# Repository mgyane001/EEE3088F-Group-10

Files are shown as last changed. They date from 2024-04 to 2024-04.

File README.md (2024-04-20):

# EEE3088F Group 10 Micro-Mouse Project 2024

## Project Overview
The goal of the Micro-Mouse Project is designing and building a maze-solving robot, inspired by the principles and competition of Micro-Mouse robots. This project focuses on the hardware development of the robot, particularly the sensing and power subsystems, while integrating provided processor and motherboard modules.

### Components
- **Processor Module:** Utilizes a STM32L476 microcontroller for processing and programming.
- **Motherboard Module:** Serves as the foundational circuit board connecting all the other modules.
- **Sensing Module:** Designed to detect obstacles, aiding the robot in navigation.
- **Power Module:** Manages power distribution, motor operation, and battery charging.

## Installation & Setup
This section will guide you through setting up your development environment and assembling the Micro-Mouse robot.

### Prerequisites
- STM32CubeIDE for firmware development.
- Basic soldering equipment and electronic component handling knowledge.
- KiCad or any other electronics CAD software

### Assembly Instructions
1. **Processor & Motherboard Connection:** Start by connecting the processor module to the motherboard using the provided pin headers.
2. **Sensing Module Assembly:** Follow the schematic in `Docs/Sensing_Module_Schematic.pdf` to assemble your sensing module. Attach it to the motherboard as indicated.
3. **Power Module Assembly:** Assemble the power module according to `Docs/Power_Module_Schematic.pdf` and attach it to the designated motherboard location.
4. **Final Assembly:** Secure all connections and mount the assembled motherboard into the chassis and connect the motors and battery.

## Usage
To operate the Micro-Mouse:
1. **Firmware Upload:** Use STM32CubeIDE to open the project from `Firmware/` and flash it onto the processor module.
2. **Power On:** Switch on the Micro-Mouse using the power module's ON/OFF switch.
3. **Maze Testing:** Place the Micro-Mouse at the start of a maze and observe its operation and maze-solving capability.

## Contributing
We welcome contributions to the Micro-Mouse Project! If you have suggestions, improvements, or bug fixes, please follow the steps below:
1. Fork the repository.
2. Create a new branch (`git checkout -b feature/AmazingFeature`).
3. Commit your changes (`git commit -m 'Add some AmazingFeature'`).
4. Push to the branch (`git push origin feature/AmazingFeature`).
5. Open a pull request.

## Project Structure
- `/Firmware`: Contains all firmware code for the Micro-Mouse.
- `/Docs`: Documentation, including module schematics and assembly guides.
- `/Tools`: Auxiliary tools for development and testing.
- `/Designs`: CAD designs for optional chassis and mechanical parts.

## Support
For support, please open an issue in the repository or contact the project maintainers directly via email.

## Acknowledgements
- **Veritasium:** For the inspirational content on Micro-Mouse robots.
- **STM32L476 Community:** For resources and support in firmware development.

## License
This project is licensed under the MIT License - see the `LICENSE` file for details.

---

We hope this project inspires and educates all participants and observers alike. Happy building!

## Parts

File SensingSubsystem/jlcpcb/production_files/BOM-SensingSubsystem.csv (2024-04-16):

Comment | Designator | Footprint | LCSC
BS170 | Q4,Q5,Q6 | TO-92_Inline | C111691
4.7u | C1,C2,C3 | C_0805_2012Metric | C19666
100 | R10,R4,R7 | R_0603_1608Metric | C22775
22 | R12,R6,R9 | R_0603_1608Metric | C23345
47k | R11,R5,R8 | R_0603_1608Metric | C25819
SFH 309 FA | Q1,Q2,Q3 | LED_D3.0mm_Horizontal_O1.27mm_Z10.0mm | C2900253
1.8k | R1,R2,R3 | R_0603_1608Metric | C4177
TSAL6200 | D1,D2,D3 | LED_D5.0mm_Horizontal_O1.27mm_Z15.0mm | C55528

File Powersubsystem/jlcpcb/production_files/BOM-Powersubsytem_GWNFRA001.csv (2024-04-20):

Comment | Designator | Footprint | LCSC
2.2uF | C1 | C_0402_1005Metric | C12530
BQ24092DGQR | U2 | IC_XTR111AIDGQR | C133237
10uF | C8 | C_0402_1005Metric | C15195
1k | R2,R4,R6,R7 | BO_CR0603 | C21190
2k | R3 | BO_CR0603 | C22975
100k | R1,R5 | BO_CR0603 | C25803
TS-1187A-B-A-B | S1 | SW_TS-1187A-B-A-B | C318884
DRV8833PWPR | U3 | IC_DRV8833PWPR | C50506
1uF | C6,C7 | C_0402_1005Metric | C52923
0.01uF | C4 | C_01005_0402Metric

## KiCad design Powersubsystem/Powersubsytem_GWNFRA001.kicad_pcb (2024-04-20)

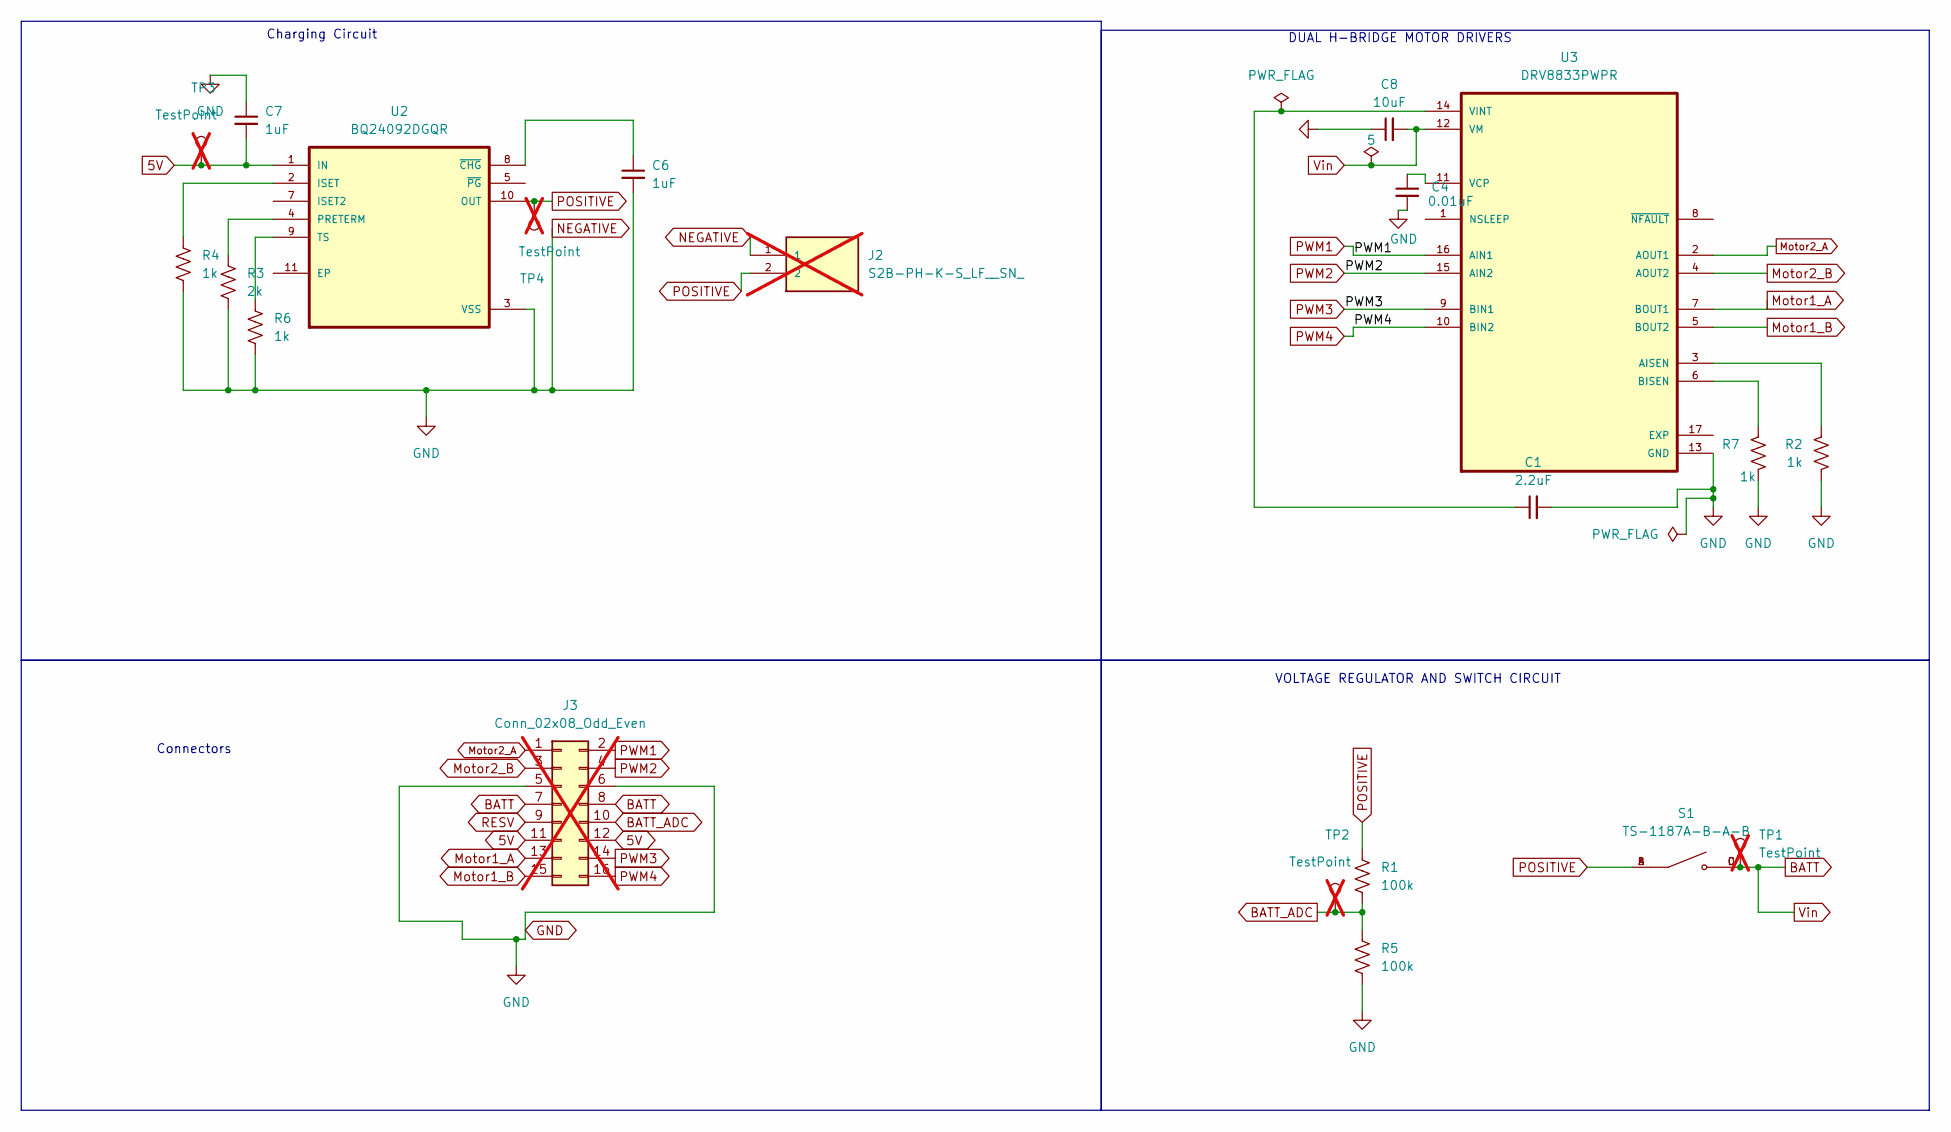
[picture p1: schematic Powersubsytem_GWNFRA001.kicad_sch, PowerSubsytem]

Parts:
C1: 2.2uF; C_0402_1005Metric
C4: 0.01uF; C_01005_0402Metric
C6, C7: 1uF; C_0402_1005Metric
C8: 10uF; C_0402_1005Metric
J2: S2B-PH-K-S_LF__SN_; JST_S2B-PH-K-S_LF__SN_; not fitted
J3: Conn_02x08_Odd_Even; PinHeader_2x08_P2.54mm_Vertical; not fitted
R1, R5: 100k; BO_CR0603
R2, R4, R6, R7: 1k; BO_CR0603
R3: 2k; BO_CR0603
S1: TS-1187A-B-A-B; SW_TS-1187A-B-A-B; PARTREV A0
TP1, TP2, TP3, TP4: TestPoint; TestPoint_THTPad_D1.0mm_Drill0.5mm; not fitted
U2: BQ24092DGQR; IC_XTR111AIDGQR
U3: DRV8833PWPR; IC_DRV8833PWPR; PARTREV E; LCSC C50506

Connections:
5V: C7.2, J3.11, J3.12, TP3.1, U2.1 (IN)
BATT: C8.2, J3.7, J3.8, S1.C, S1.D, TP1.1, U3.12 (VM)
BATT_ADC: J3.10, R1.2, R5.1, TP2.1
GND: C1.2, C4.2, C6.2, C7.1, C8.1, J2.1, J3.5, J3.6, R2.2, R3.2, R4.2, R5.2, R6.2, R7.2, U2.3 (VSS), U3.13 (GND)
Motor1_A: J3.13, U3.7 (BOUT1)
Motor1_B: J3.15, U3.5 (BOUT2)
Motor2_A: J3.1, U3.2 (AOUT1)
Motor2_B: J3.3, U3.4 (AOUT2)
unnamed: R4.1, U2.2 (ISET)
unnamed: R3.1, U2.4 (PRETERM)
unnamed: R6.1, U2.9 (TS)
unnamed: C6.1, U2.8 (~CHG)
unnamed: R2.1, U3.3 (AISEN)
unnamed: R7.1, U3.6 (BISEN)
unnamed: C4.1, U3.11 (VCP)
unnamed: C1.1, U3.14 (VINT)
POSITIVE: J2.2, R1.1, S1.A, S1.B, TP4.1, U2.10 (OUT)
PWM1: J3.2, U3.16 (AIN1)
PWM2: J3.4, U3.15 (AIN2)
PWM3: J3.14, U3.9 (BIN1)
PWM4: J3.16, U3.10 (BIN2)
RESV: J3.9

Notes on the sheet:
Charging Circuit
VOLTAGE REGULATOR AND SWITCH CIRCUIT
Connectors
DUAL H-BRIDGE MOTOR DRIVERS

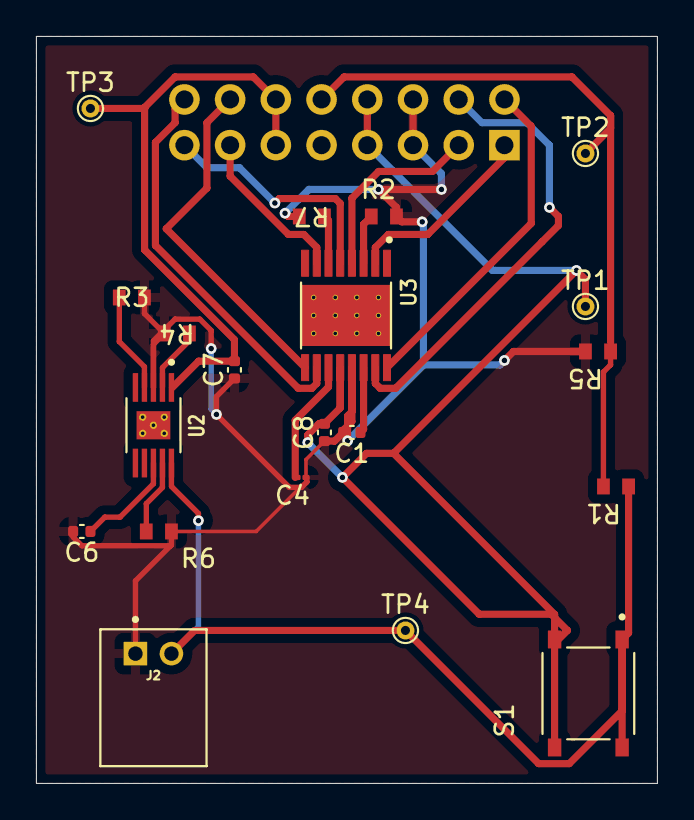
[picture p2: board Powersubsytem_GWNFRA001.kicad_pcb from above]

Board: 2 copper layers, 34.5 x 41.5 mm, 21 parts (1 on the bottom side), 21 nets.

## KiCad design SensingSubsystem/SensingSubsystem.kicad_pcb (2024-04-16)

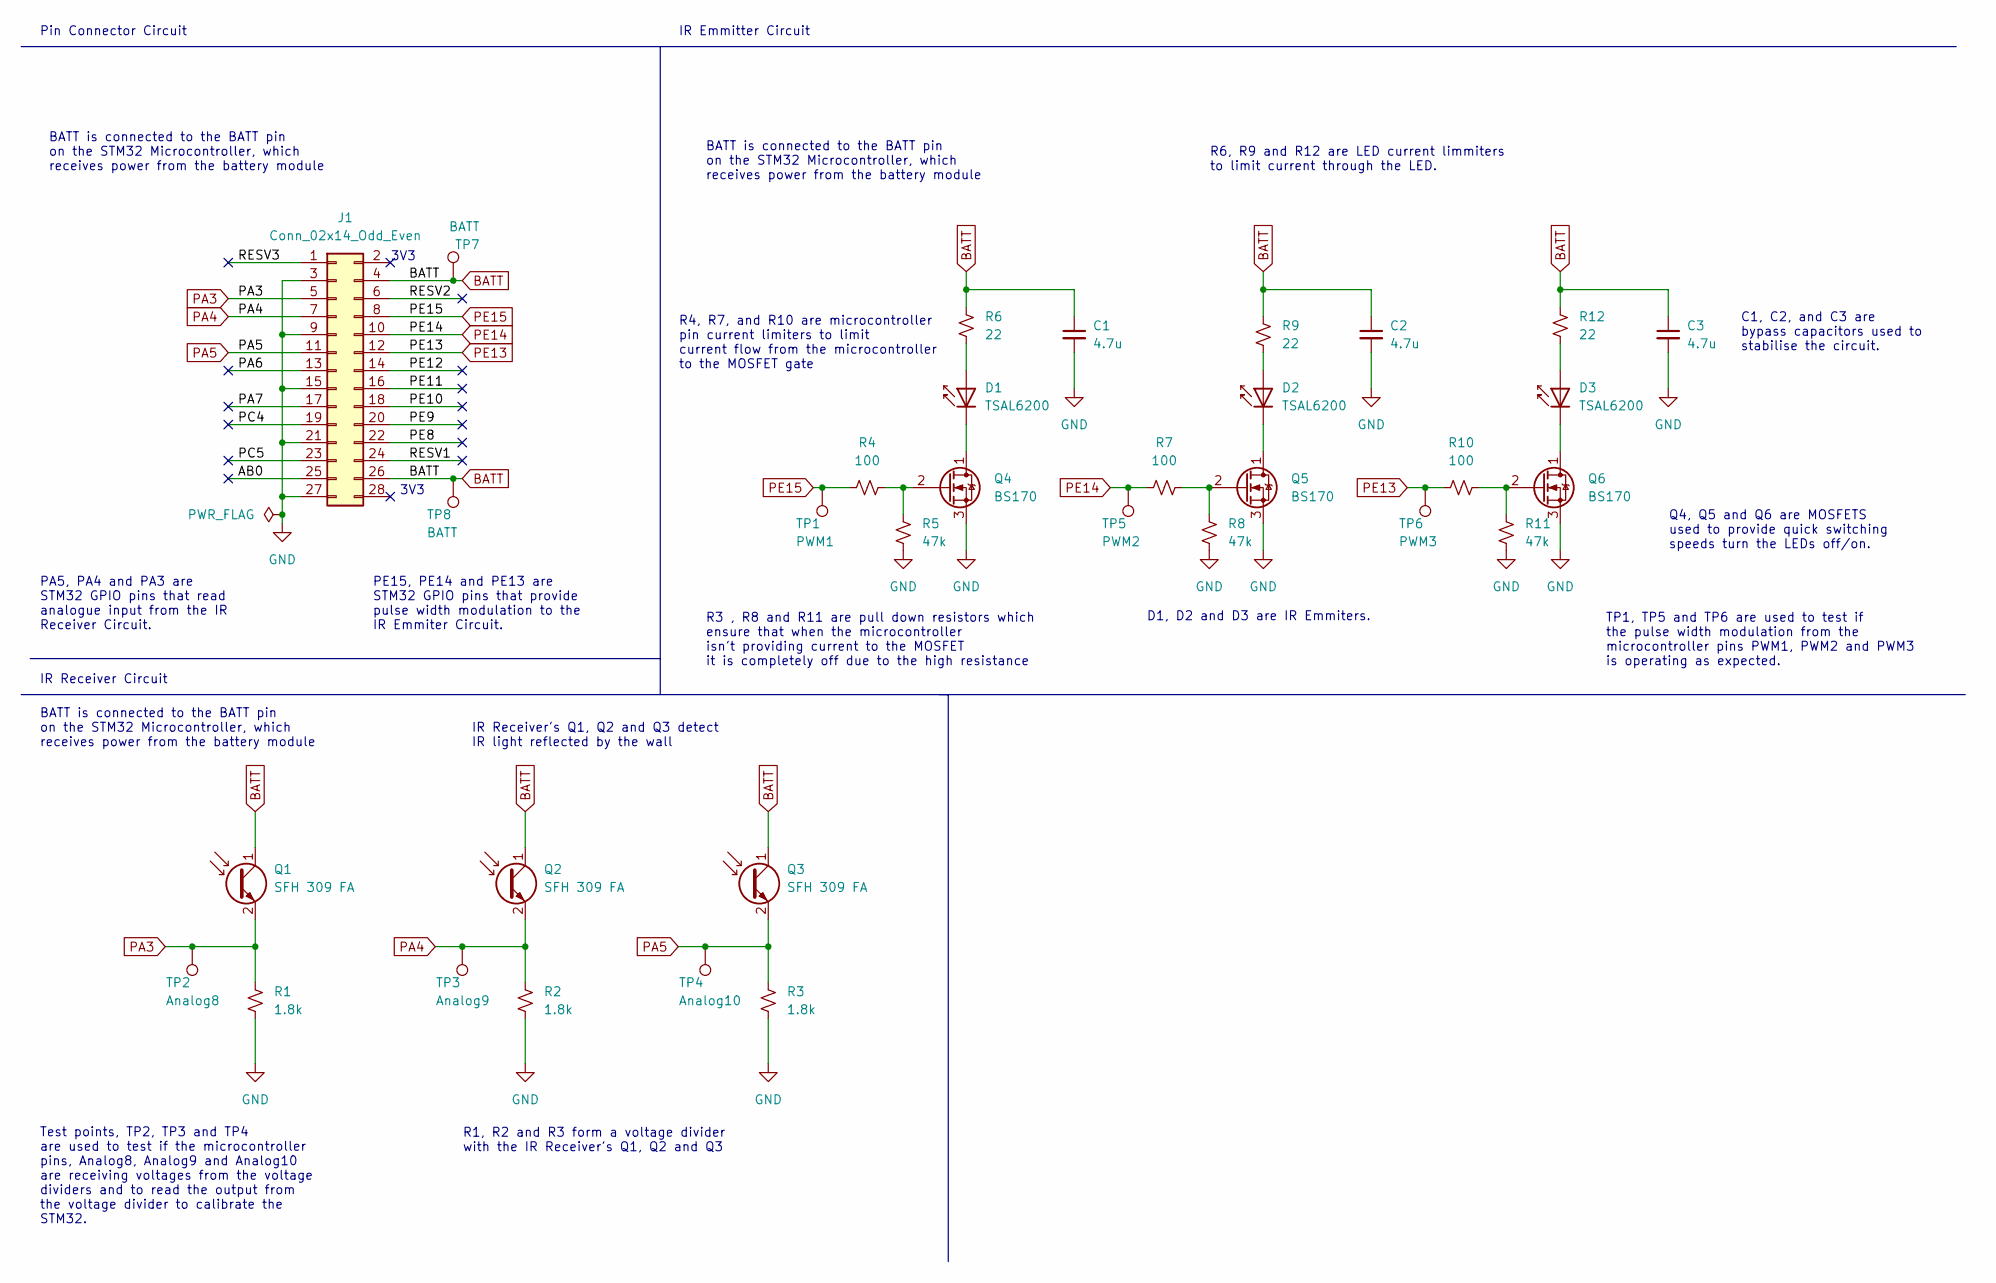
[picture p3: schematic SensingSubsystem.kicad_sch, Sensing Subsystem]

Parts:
C1, C2, C3: 4.7u; C_0805_2012Metric
D1, D2, D3: TSAL6200; LED_D5.0mm_Horizontal_O1.27mm_Z15.0mm
J1: Conn_02x14_Odd_Even; PinHeader_2x14_P2.54mm_Vertical
Q1, Q2, Q3: SFH 309 FA; LED_D3.0mm_Horizontal_O1.27mm_Z10.0mm
Q4, Q5, Q6: BS170; TO-92_Inline
R1, R2, R3: 1.8k; R_0603_1608Metric
R4, R7, R10: 100; R_0603_1608Metric
R5, R8, R11: 47k; R_0603_1608Metric
R6, R9, R12: 22; R_0603_1608Metric
TP1: PWM1; TestPoint_THTPad_D1.0mm_Drill0.5mm
TP2: Analog8; TestPoint_THTPad_D1.0mm_Drill0.5mm
TP3: Analog9; TestPoint_THTPad_D1.0mm_Drill0.5mm
TP4: Analog10; TestPoint_THTPad_D1.0mm_Drill0.5mm
TP5: PWM2; TestPoint_THTPad_D1.0mm_Drill0.5mm
TP6: PWM3; TestPoint_THTPad_D1.0mm_Drill0.5mm
TP7, TP8: BATT; TestPoint_THTPad_D1.0mm_Drill0.5mm

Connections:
/AB0: J1.25
/PA6: J1.13
/PA7: J1.17
/PC4: J1.19
/PC5: J1.23
/PE8: J1.22
/PE9: J1.20
/PE10: J1.18
/PE11: J1.16
/PE12: J1.14
/RESV1: J1.24
/RESV2: J1.6
/RESV3: J1.1
BATT: C1.1, C2.1, C3.1, J1.4, J1.26, Q1.1 (C), Q2.1 (C), Q3.1 (C), R6.1, R9.1, R12.1, TP7.1, TP8.1
GND: C1.2, C2.2, C3.2, J1.3, J1.9, J1.15, J1.21, J1.27, Q4.3 (S), Q5.3 (S), Q6.3 (S), R1.2, R2.2, R3.2, R5.1, R8.1, R11.1
unnamed: D1.1 (K), Q4.1 (D)
unnamed: D1.2 (A), R6.2
unnamed: D2.1 (K), Q5.1 (D)
unnamed: D2.2 (A), R9.2
unnamed: D3.1 (K), Q6.1 (D)
unnamed: D3.2 (A), R12.2
unnamed: Q4.2 (G), R4.2, R5.2
unnamed: Q5.2 (G), R7.2, R8.2
unnamed: Q6.2 (G), R10.2, R11.2
PA3: J1.5, Q1.2 (E), R1.1, TP2.1
PA4: J1.7, Q2.2 (E), R2.1, TP3.1
PA5: J1.11, Q3.2 (E), R3.1, TP4.1
PE13: J1.12, R10.1, TP6.1
PE14: J1.10, R7.1, TP5.1
PE15: J1.8, R4.1, TP1.1

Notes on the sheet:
R3 , R8 and R11 are pull down resistors which ensure that when the microcontroller isn't providing current to the MOSFET it is completely off due to the high resistance
IR Emmitter Circuit
C1, C2, and C3 are bypass capacitors used to stabilise the circuit.
PE15, PE14 and PE13 are STM32 GPIO pins that provide pulse width modulation to the IR Emmiter Circuit.
3V3
R6, R9 and R12 are LED current limmiters to limit current through the LED.
TP1, TP5 and TP6 are used to test if the pulse width modulation from the microcontroller pins PWM1, PWM2 and PWM3 is operating as expected.
BATT is connected to the BATT pin on the STM32 Microcontroller, which receives power from the battery module
Test points, TP2, TP3 and TP4 are used to test if the microcontroller pins, Analog8, Analog9 and Analog10 are receiving voltages from the voltage dividers and to read the output from the voltage divider to calibrate the STM32.
Pin Connector Circuit
PA5, PA4 and PA3 are STM32 GPIO pins that read analogue input from the IR Receiver Circuit.
IR Receiver's Q1, Q2 and Q3 detect IR light reflected by the wall
D1, D2 and D3 are IR Emmiters.
IR Receiver Circuit
Q4, Q5 and Q6 are MOSFETS used to provide quick switching speeds turn the LEDs off/on.
R4, R7, and R10 are microcontroller pin current limiters to limit current flow from the microcontroller to the MOSFET gate
R1, R2 and R3 form a voltage divider with the IR Receiver's Q1, Q2 and Q3

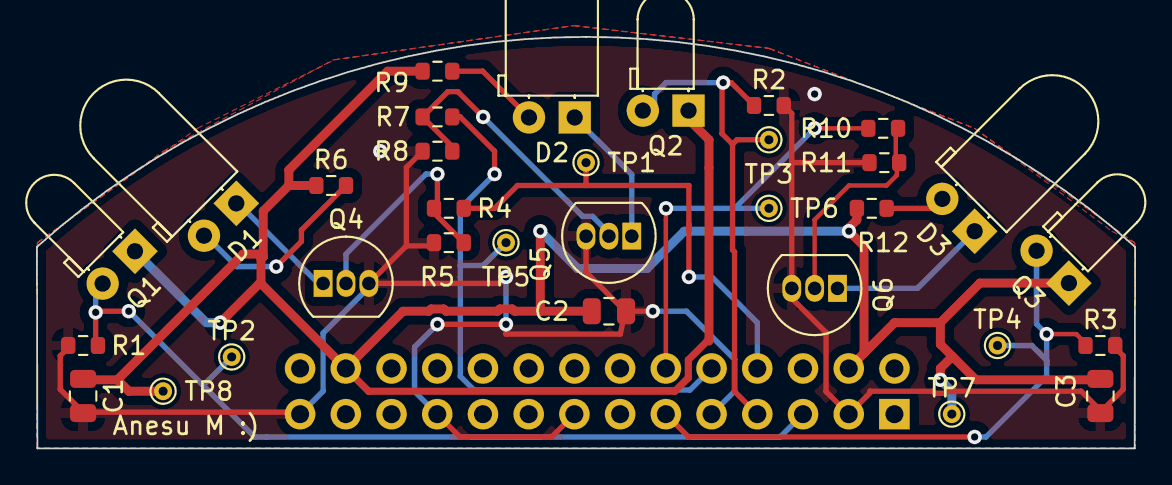
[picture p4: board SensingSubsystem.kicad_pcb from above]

Board: 2 copper layers, 61.0 x 22.9 mm, 33 parts (1 on the bottom side), 17 nets.

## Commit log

2024-04-16 Sensing subsystem initial commit
    [BOM-SensingSubsystem.csv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]
2024-04-20 Power Subsystem
    [BOM-Powersubsytem_GWNFRA001.csv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]
